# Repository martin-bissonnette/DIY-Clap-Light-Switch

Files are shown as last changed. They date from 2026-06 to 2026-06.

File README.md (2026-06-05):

# DIY-Clap-Light-Switch

An ESP32-C3 powered light switch that toggles on a double-clap, using an INMP441 MEMS microphone for clap detection 
and a GA12-N20 micro DC motor to physically actuate the switch. Designed for a 3D-printed enclosure and powered from 
a single 18650 Li-ion cell on a BreadVolt with 5V and 3.3V.

## Features
- **Double-clap detection** — distinguishes a genuine double-clap from background noise using configurable timing windows and noise max and min settings
- **Physical actuation** — GA12-N20 geared motor drives the switch lever; limit switches define the ON/OFF positions
- **Overcurrent recovery** — automatically resets the motor driver's SLEEP pin after fault conditions
- **Battery powered** — TPS63020 buck-boost regulates 3.3 V across the full 18650 discharge curve
- **Variable cooldown window** — prevents false re-triggers immediately after an action, initially triggered by motor noises next to microphone

## Hardware
| Component | Part |
|--- |---|
| MCU | ESP32-C3 SuperMini |
| Microphone | INMP441 MEMS (I2S) |
| Motor | GA12-N20 micro DC geared motor |
| Motor driver | Dual H-bridge (IN1–4 / OUT1–4 / EEP / ULT pinout) |
| Power module | EC Buying XL63020-3.3 (TPS63020-based buck-boost, 3.3 V fixed) |
| Battery | 18650 Li-ion cell (external charger workflow) |
| Limit switches  | Salvaged 3D printer endstop switches × 2 |
| Enclosure | Custom 3D-printed (see CAD) |

### Pin Assignments
| Signal | GPIO |
|--- |---|
| I2S SCK (INMP441) | 2 |
| I2S WS (INMP441) | 3 |
| I2S SD (INMP441) | 4 |
| Motor IN1 | 5 |
| Motor IN2 | 6 |
| Motor EEP / SLEEP | 7 |
| Limit switch — ON position | 8 |
| Limit switch — OFF position | 9 |

Limit switches are wired to GND and use INPUT_PULLUP; they read LOW when triggered.

## Firmware
The sketch lives in `/clap_light_switch.ino` and targets the **Arduino IDE 2.x** with the **ESP32 Arduino core**.

### Key Tuning Parameters
```cpp
#define CLAP_THRESHOLD  80000000L   // Amplitude required to register a clap
#define AMP_MAP_LOW     0L          // Amplitude mapping range low
#define AMP_MAP_HIGH    60000000L   // Amplitude mapping range high
#define CLAP_MIN_GAP    150         // ms — minimum gap between the two claps
#define CLAP_MAX_GAP    800         // ms — maximum gap for a valid double-clap
#define COOLDOWN_MS     3000        // ms — lockout after an action
#define MOTOR_TIMEOUT   3000        // ms — fallback if a limit switch is not reached
```

### INMP441 Notes

This specific ESP32-C3 SuperMini clone requires:
- `I2S_CHANNEL_FMT_ALL_LEFT` (standard `RIGHT_LEFT` format produces silence)
- 16000 Hz sample rate

### Building & Flashing
1. Install the [ESP32 Arduino core](https://docs.espressif.com/projects/arduino-esp32/en/latest/installing.html)
2. Select **ESP32C3 Dev Module** as the board
3. Open `firmware/clap_light_switch/clap_light_switch.ino`
4. Flash via USB

======================================================================================

## PCB Design (In Progress)

Target: 2-layer board, ~55 × 90 mm, designed using KiCad.

| Component | Mounting |
|--- |---|
| ESP32-C3 SuperMini | Removable pin headers |
| INMP441 | Removable pin headers |
| DRV8833 motor driver | Bare HTSSOP-16 (hand-solderable) |
| TPS63020 power module | Removable pin headers |
| Motor / battery / limit switches | 3.5 mm pitch screw terminals |

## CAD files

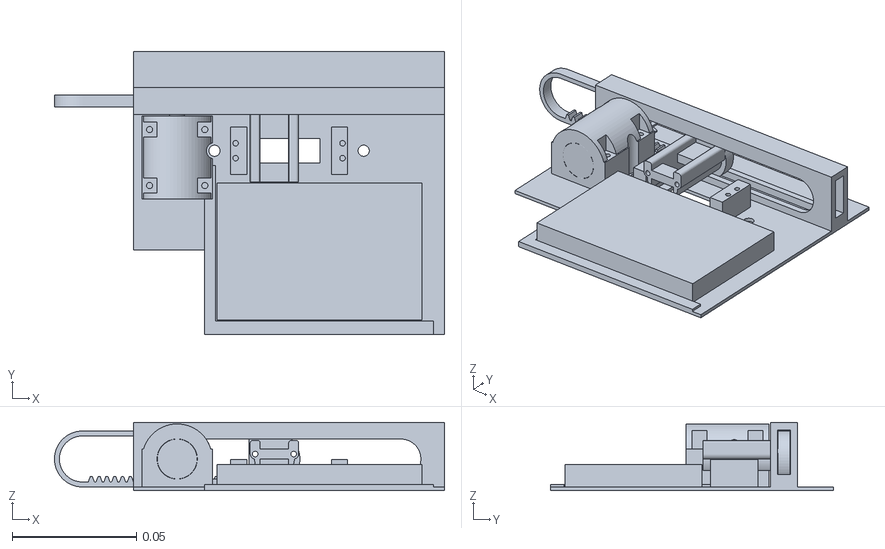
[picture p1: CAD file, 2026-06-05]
CAD/DIY Clap Light Switch Assembly.stl
0.157 x 0.114 x 0.0275

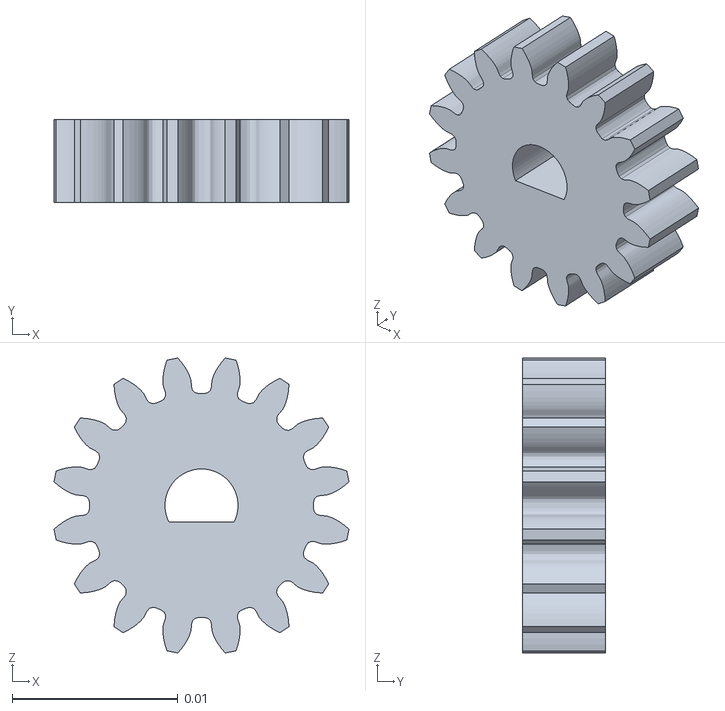
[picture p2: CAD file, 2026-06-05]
CAD/Spur gear (16 teeth).stl
0.0178 x 0.005 x 0.0178

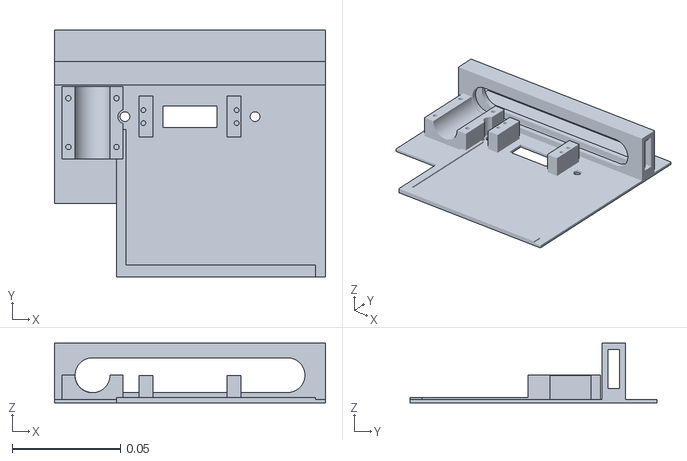
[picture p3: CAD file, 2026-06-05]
CAD/Plate Body.stl
0.125 x 0.114 x 0.0275

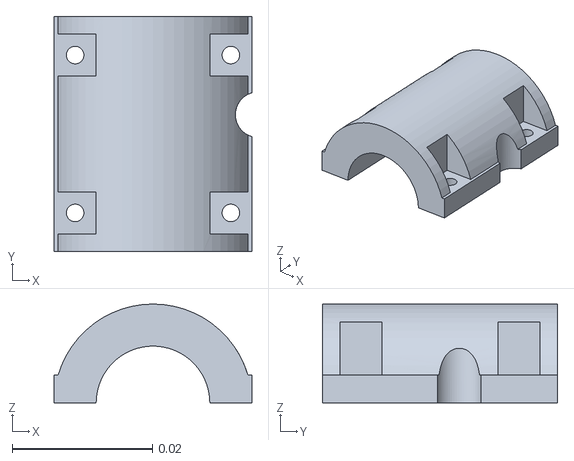
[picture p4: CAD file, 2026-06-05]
CAD/Motor Mount Top.stl
0.0282 x 0.0335 x 0.0141

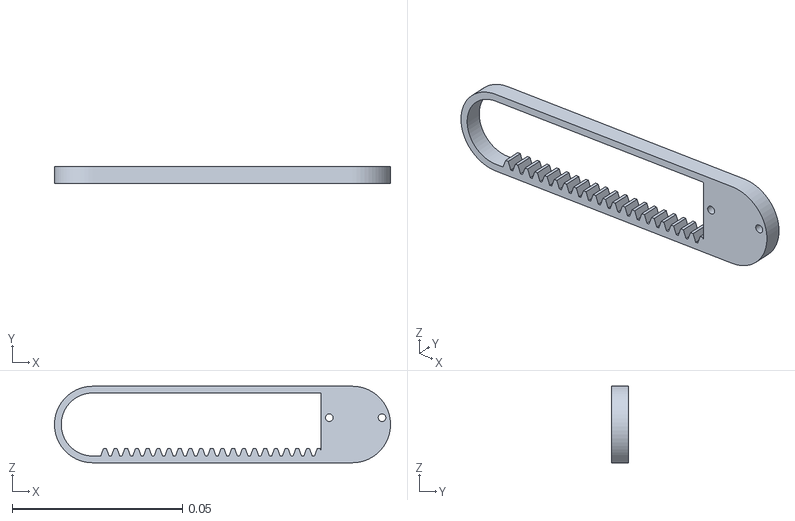
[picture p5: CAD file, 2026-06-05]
CAD/Rack (25 teeth).stl
0.0987 x 0.005 x 0.0225

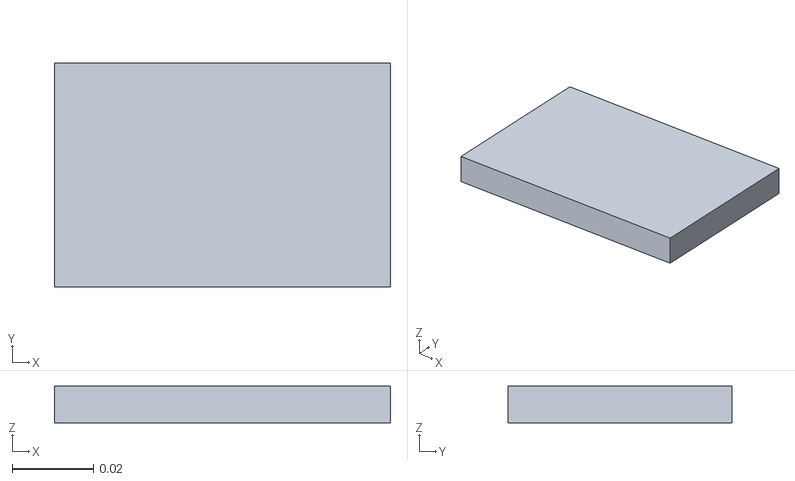
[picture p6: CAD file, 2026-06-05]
CAD/Breadboard.stl
0.0825 x 0.055 x 0.009

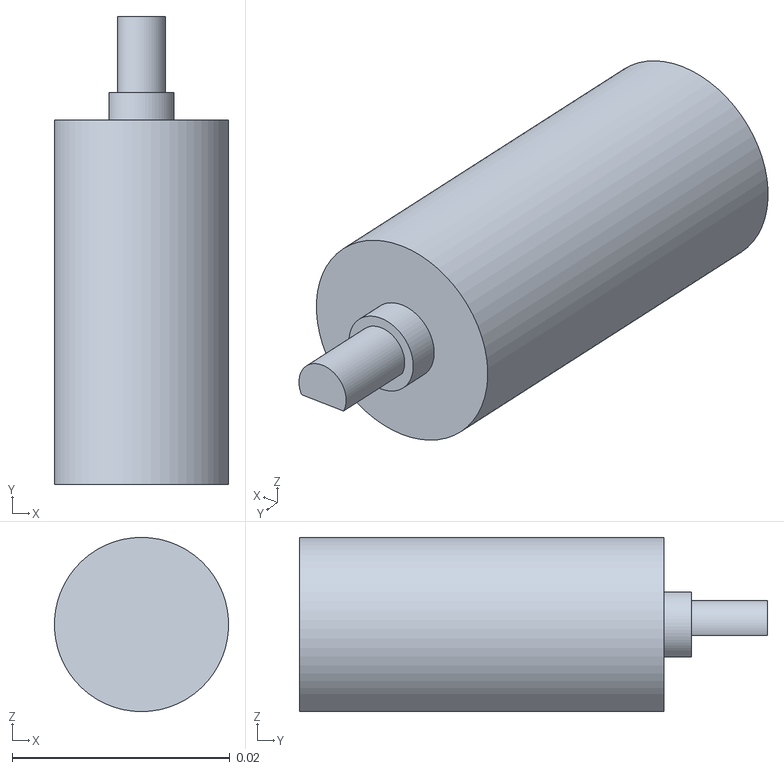
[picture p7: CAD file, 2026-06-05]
CAD/Motor.stl
0.016 x 0.043 x 0.016

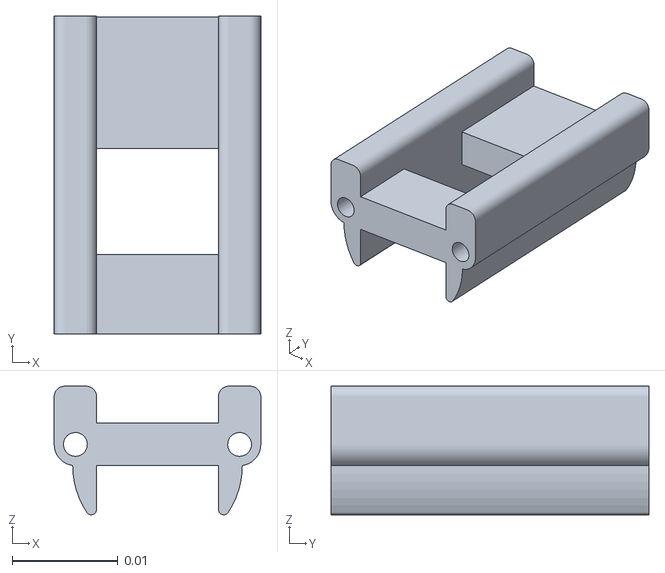
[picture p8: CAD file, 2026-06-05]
CAD/Switch Claw.stl
0.0195 x 0.03 x 0.0121

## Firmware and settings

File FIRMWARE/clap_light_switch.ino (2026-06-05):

/*
 * Clap-Activated Light Switch
 * ============================
 * ESP32-C3 SuperMini + INMP441 MEMS Mic + GA12-N20 Motor via H-Bridge
 *
 * Hardware:
 *   - MCU:        ESP32-C3 SuperMini
 *   - Mic:        INMP441 (I2S)
 *   - Motor:      GA12-N20 micro DC motor
 *   - Driver:     Dual H-bridge (IN1-4 / OUT1-4 / EEP / ULT)
 *   - Power:      TPS63020 buck-boost @ 3.3V (EC Buying XL63020-3.3 module)
 *   - Limits:     Salvaged 3D printer endstop switches
 *
 * Pin Assignments:
 *   INMP441  SCK  → GPIO2
 *   INMP441  WS   → GPIO3
 *   INMP441  SD   → GPIO4
 *   Motor    IN1  → GPIO5
 *   Motor    IN2  → GPIO6
 *   Motor    EEP  → GPIO7  (SLEEP/fault-reset pin)
 *   Limit SW 1    → GPIO8  (INPUT_PULLUP, active LOW = fully ON position)
 *   Limit SW 2    → GPIO9  (INPUT_PULLUP, active LOW = fully OFF position)
 */

#include <driver/i2s.h>

// ── I2S / Microphone ──────────────────────────────────────────────────────────
#define I2S_PORT        I2S_NUM_0
#define I2S_SCK_PIN     2
#define I2S_WS_PIN      3
#define I2S_SD_PIN      4
#define SAMPLE_RATE     16000
#define SAMPLE_BUFFER   512

// ── Motor driver ──────────────────────────────────────────────────────────────
#define MOTOR_IN1       5
#define MOTOR_IN2       6
#define MOTOR_EEP       7   // SLEEP / overcurrent-fault reset

// ── Limit switches (active LOW with INPUT_PULLUP) ─────────────────────────────
#define LIMIT_ON        8   // Triggered when light is fully ON
#define LIMIT_OFF       9   // Triggered when light is fully OFF
#define MOTOR_TIMEOUT   3000  // ms before giving up if limit not reached

// ── Clap detection tuning ─────────────────────────────────────────────────────
#define CLAP_THRESHOLD  80000000L
#define AMP_MAP_LOW     0L
#define AMP_MAP_HIGH    60000000L
#define CLAP_MIN_GAP    150   // ms  — minimum gap between two claps
#define CLAP_MAX_GAP    800   // ms  — maximum gap for double-clap
#define COOLDOWN_MS     3000  // ms  — ignore claps after an action

// ── State ─────────────────────────────────────────────────────────────────────
bool lightIsOn = false;

unsigned long lastClapTime   = 0;
unsigned long lastActionTime = 0;
bool          waitingSecond  = false;

// ─────────────────────────────────────────────────────────────────────────────
void setupI2S() {
  i2s_config_t cfg = {
    .mode                 = (i2s_mode_t)(I2S_MODE_MASTER | I2S_MODE_RX),
    .sample_rate          = SAMPLE_RATE,
    .bits_per_sample      = I2S_BITS_PER_SAMPLE_32BIT,
    .channel_format       = I2S_CHANNEL_FMT_ALL_LEFT,   // Required for this ESP32-C3 clone
    .communication_format = I2S_COMM_FORMAT_STAND_I2S,
    .intr_alloc_flags     = ESP_INTR_FLAG_LEVEL1,
    .dma_buf_count        = 4,
    .dma_buf_len          = SAMPLE_BUFFER,
    .use_apll             = false,
    .tx_desc_auto_clear   = false,
    .fixed_mclk           = 0
  };

  i2s_pin_config_t pins = {
    .bck_io_num   = I2S_SCK_PIN,
    .ws_io_num    = I2S_WS_PIN,
    .data_out_num = I2S_PIN_NO_CHANGE,
    .data_in_num  = I2S_SD_PIN
  };

  i2s_driver_install(I2S_PORT, &cfg, 0, NULL);
  i2s_set_pin(I2S_PORT, &pins);
}

void setupMotor() {
  pinMode(MOTOR_IN1, OUTPUT);
  pinMode(MOTOR_IN2, OUTPUT);
  pinMode(MOTOR_EEP, OUTPUT);
  resetDriver();
}

// Wake the H-bridge from sleep / clear overcurrent fault
void resetDriver() {
  digitalWrite(MOTOR_EEP, LOW);
  delay(10);
  digitalWrite(MOTOR_EEP, HIGH);
}

void motorStop() {
  digitalWrite(MOTOR_IN1, LOW);
  digitalWrite(MOTOR_IN2, LOW);
}

void motorForward() {
  resetDriver();
  digitalWrite(MOTOR_IN1, HIGH);
  digitalWrite(MOTOR_IN2, LOW);
}

void motorReverse() {
  resetDriver();
  digitalWrite(MOTOR_IN1, LOW);
  digitalWrite(MOTOR_IN2, HIGH);
}

// Drive motor until the target limit switch triggers (or timeout)
void driveToLimit(int limitPin, void (*motorDir)()) {
  unsigned long start = millis();
  motorDir();
  while (digitalRead(limitPin) == HIGH) {
    if (millis() - start > MOTOR_TIMEOUT) {
      Serial.println("⚠ Motor timeout — limit switch not reached");
      break;
    }
    delay(10);
  }
  motorStop();
}

void turnLightOn() {
  Serial.println("→ Turning ON");
  driveToLimit(LIMIT_ON, motorForward);
  lightIsOn = true;
}

void turnLightOff() {
  Serial.println("→ Turning OFF");
  driveToLimit(LIMIT_OFF, motorReverse);
  lightIsOn = false;
}

long readAmplitude() {
  int32_t samples[SAMPLE_BUFFER];
  size_t  bytesRead = 0;

  i2s_read(I2S_PORT, samples, sizeof(samples), &bytesRead, portMAX_DELAY);

  int count = bytesRead / sizeof(int32_t);
  long sum  = 0;
  for (int i = 0; i < count; i++) {
    sum += abs(samples[i] >> 8);   // scale 32-bit sample
  }
  return (count > 0) ? sum / count : 0;
}

// ─────────────────────────────────────────────────────────────────────────────
void setup() {
  Serial.begin(115200);
  Serial.println("Clap Light Switch — booting");

  pinMode(LIMIT_ON,  INPUT_PULLUP);
  pinMode(LIMIT_OFF, INPUT_PULLUP);

  setupI2S();
  setupMotor();

  Serial.println("Ready — double-clap to toggle light");
}

void loop() {
  long amp = readAmplitude();

  // Optional: uncomment to calibrate thresholds via Serial Monitor
  // Serial.println(amp);

  if (amp < CLAP_THRESHOLD) return;

  unsigned long now = millis();

  // Ignore claps during cooldown
  if (now - lastActionTime < COOLDOWN_MS) return;

  if (!waitingSecond) {
    // First clap detected — start the double-clap window
    lastClapTime  = now;
    waitingSecond = true;
  } else {
    unsigned long gap = now - lastClapTime;

    if (gap >= CLAP_MIN_GAP && gap <= CLAP_MAX_GAP) {
      // Valid double-clap!
      waitingSecond = false;
      lastActionTime = now;
      Serial.printf("Double-clap! gap=%lums\n", gap);

      if (lightIsOn) {
        turnLightOff();
      } else {
        turnLightOn();
      }
    } else if (gap > CLAP_MAX_GAP) {
      // Window expired — treat this clap as a new first clap
      lastClapTime = now;
    }
    // gap < MIN_GAP: too fast, ignore (stay in waitingSecond state)
  }

  // Reset double-clap window if it expires without a second clap
  if (waitingSecond && (millis() - lastClapTime > CLAP_MAX_GAP)) {
    waitingSecond = false;
  }
}

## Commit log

2026-06-05 Enhance README with project details and specifications
    Expanded the README to include detailed project features, hardware specifications, pin assignments, firmware information, and PCB design details.
2026-06-05 Uploaded arduino .in script
2026-06-05 Added CAD Assembly
    [DIY Clap Light Switch Assembly.stl]
2026-06-05 Create .gitkeep for CAD Folder
2026-06-05 Refactored file structure and added CAD fiels
    [Breadboard.stl, DIY Clap Light Switch Assembly.stl, Motor Mount Top.stl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]
